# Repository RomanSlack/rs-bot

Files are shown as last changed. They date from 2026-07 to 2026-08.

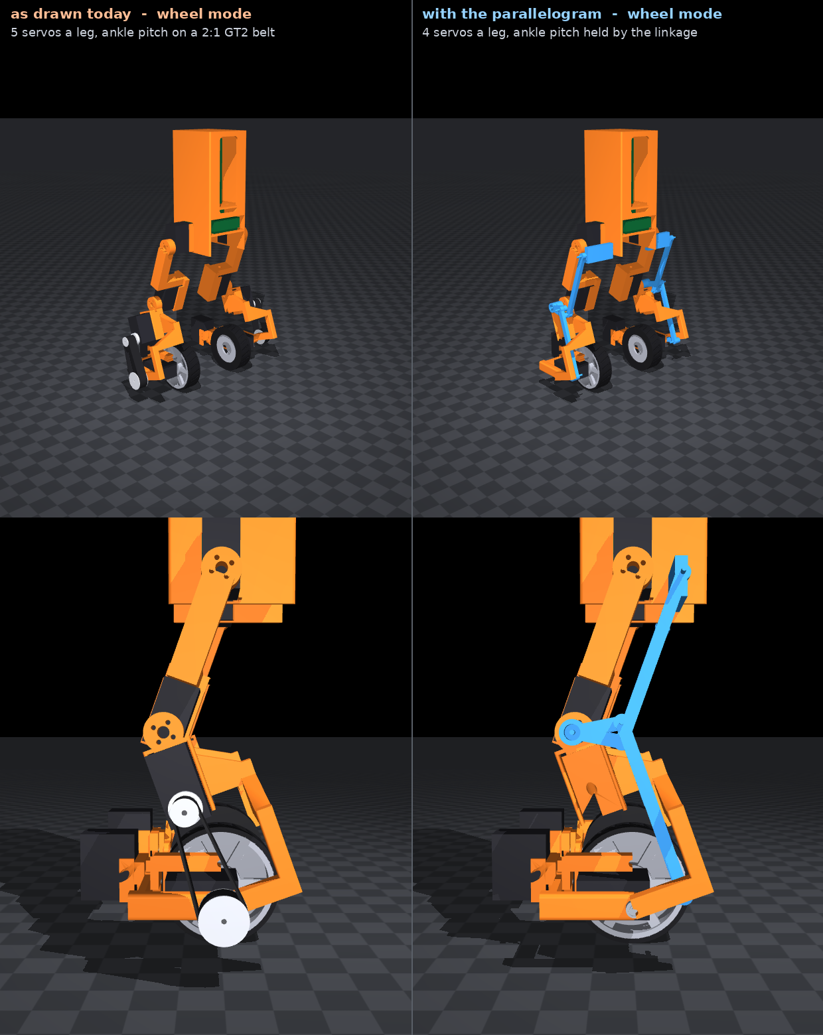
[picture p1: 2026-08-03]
renders/servos-before-after-wheel.png

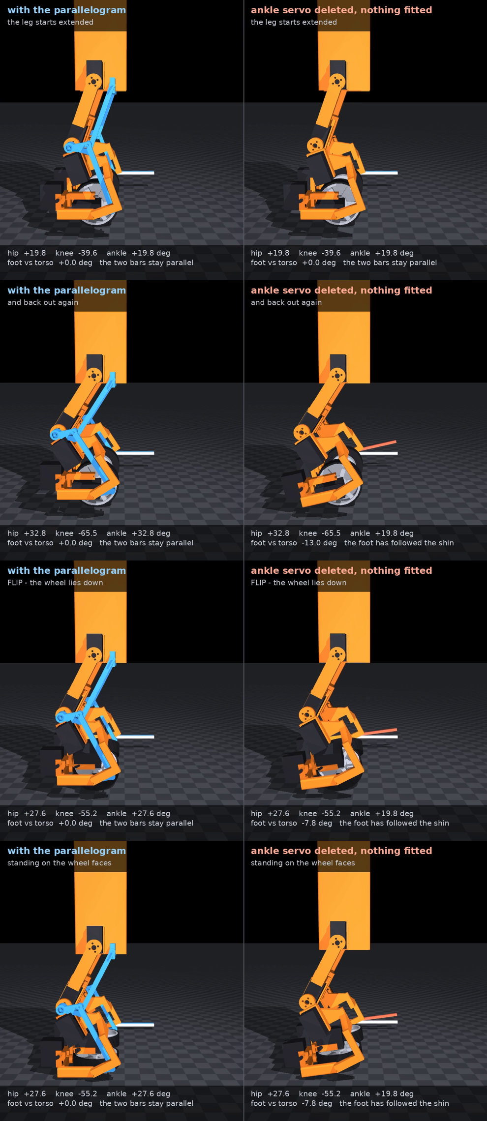
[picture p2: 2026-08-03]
renders/linkage-explained.png

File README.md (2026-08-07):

# rs-bot

A desk-scale wheeled biped whose wheels rotate flat to become its feet.
~43 cm tall, ~1.80 kg.

It balances on two wheels like a tiny Handle, and when it needs to hold still
or manipulate something, each ankle rolls 90 degrees: the wheels lie down and
their 80 mm faces become the soles. It then stands there statically with the
balance loop switched off. That transition is the point of the project - a
wheeled biped that can stop fighting its own balance loop before it reaches for
something - and the wheel-as-foot trick means it costs one joint per leg and no
extra parts.

Nothing here is bought yet. Everything runs in MuJoCo.

## The point: one shot

**The digital twin is the deliverable, not a preview of it.** The goal is a
model so exactly 1:1 with reality that the physical build happens once: parts
ordered once, printed once, assembled once, working. No revision rounds.

That is a real constraint rather than an ambition. The operator has no printer,
so every part comes from a service at real money and one to two weeks per
attempt, and a part that has already been built around is worse than that. The
cheapest place to find a mistake is in the model, and the only mistake that
costs nothing is the one caught before the order.

So the rule the whole repo is organised around:

> **Anything the model asserts about the real robot has to be traceable to
> something measured.** A number that came from a product listing, a
> screenshot, or somebody's guess is a bug that has not surfaced yet.

This is why the verification layer in `cad/` is bigger than the parts it checks:
interference and clearance through both poses, fastener specification, driver
access, tolerance stack-up, cable routing, FEA in five materials, printability.
It is also why the status reports read as lists of things that turned out to be
wrong. Finding those is the work.

Two examples of the failure mode, both real and both from 2026-08-01. The wheel
carried a Ø20.00 pocket for a horn that measures Ø19.93, which would have made
most wheels unable to accept the part they bolt to. And forty M2 screws went
into servo case holes whose positions no drawing publishes, with four different
parts each guessing a different pattern. Neither was visible until somebody put
calipers on the real servo.

## Status

**Stages 0 and 0b (sim) - done.** Balances, drives, rejects shoves, and flips
its wheels flat to stand for 87 s with the controller off.

Gear backlash is modelled, and it is the finding that most changed the plan.
The balancer needed much lower gain plus a low-pass on the wheel command,
without which it limit-cycles through the deadzone. The passive foot stance
needed a low-gain ankle loop too, until the ankle servo was deleted: a passive
parallelogram holds the foot level mechanically and does it better than the
loop did, standing 10/10 at 4 deg of lash where the servo managed 2/10 at 2.
See [docs/backlash.md](docs/backlash.md) and
[docs/deleting-the-ankle-pitch-servo.md](docs/deleting-the-ankle-pitch-servo.md).

Stage 1 hardware has not started.

## Roadmap

Each stage has a hard exit criterion. Hit it and move on; don't polish stage N
because stage N+1 is scary.

| # | Stage | Exit criterion | State |
|---|---|---|---|
| 0 | Sim balancer | Rejects a shove, attitude recovery < 1 s | **done** |
| 0b | Sim foot transition | Flips to foot mode and stands, balancer off | **done** |
| 1 | Legs in hardware | Stands 5 min unattended, survives a poke, drives, squats | |
| 2 | Feet in hardware | 20 consecutive transitions both directions, zero falls | |
| 3 | Head camera | Teleop drive from the camera feed alone | |
| 4 | One arm | Picks up a can, 8/10 attempts | |
| 5 | Second arm | Autonomous policies | |

## Design commitments

These are fixed up front so stage 4 doesn't invalidate stage 1.

- **The whole skeleton is designed now, built in pieces.** The sim model already
  carries the arms, head and compute as torso ballast, so the legs are tuned
  against final inertia (1.80 kg) rather than a bare stage-1 mass.
- **STS3215-class serial bus servos throughout.** 2.9 N.m stall. The leg joints
  run position mode; the wheels run continuous rotation, which means the
  balancer gets a *velocity* command, not a torque. The controller is built
  around that constraint rather than pretending otherwise.
- **The wheel is the foot.** 5 DOF per leg - hip pitch, knee pitch, ankle
  pitch, ankle roll, wheel - but only FOUR servos: ankle pitch is driven by a
  passive parallelogram off the hip and knee, not by a motor. Nothing deploys, nothing folds out. Two earlier mechanisms
  with separate feet both failed for the same reason, recorded in
  docs/stage-0b.md.
- **No hopping.** Bouncing needs real torque control at ~1 kHz and QDD ankles.
  Static feet mode gets most of the value; hopping is a different robot.

## Layout

```
src/rsbot/model/rsbot.xml   MJCF model
src/rsbot/model.py          loading, leg IK, foot geometry
src/rsbot/balance.py        the balancer
src/rsbot/transition.py     wheel mode <-> foot mode state machine
src/rsbot/sim.py            headless rollouts, shove test
serve.py                    live sim in the browser: drag to orbit, scroll to zoom
render.py                   render a demo run to renders/*.mp4
scale.py                    true-scale still beside a 5 ft 9 in person
fitcheck.py                 do the real parts actually fit? (oriented-box audit)
tune.py                     coordinate-descent gain search
view.py                     native viewer (needs a working GLX display)
cad/shin.py                 build123d proof of concept: STEP + MuJoCo mesh
cad/linkage.py              the passive ankle parallelogram, drawn and swept
cad/linkage_dims.py         its geometry, with no build123d, so the sim can
                            import it too
cad/linkage_anim.py         it moving, beside a leg that has none
cad/fitview.py              the assembled robot in the browser, every gap
                            measured: toggle parts, explode, both poses
cad/servo_view.py           the servo model against the part on the desk
tests/                      exit criteria as executable checks
```

## Run it

```bash
uv run python -m pytest tests -q   # all exit criteria, ~20 min (the FEA)
uv run python serve.py             # live sim at localhost:8781, drive it around
uv run python -m cad.fitview       # the assembly at localhost:8783, gaps measured
uv run python fitcheck.py          # part interpenetration audit, both modes
uv run python render.py            # render a demo to renders/
uv run python tune.py              # re-tune balancer gains
```

Latest status report: [status/2026-08-06-status.md](status/2026-08-06-status.md).
Each one leads with what turned out to be wrong that day, which is the fastest
way back into the project.

## Documents

**What the sim proved**

- [stage-0.md](docs/stage-0.md) - the balancer numbers
- [stage-0b.md](docs/stage-0b.md) - the foot transition, and the two mechanisms
  that failed before it
- [backlash.md](docs/backlash.md) - the gear-lash results, and the finding that
  most changed the plan
- [hardware-readiness.md](docs/hardware-readiness.md) - actuator and
  control-rate margins. Are STS3215s enough, and how fast must the loop run

**The parts**

- [cad.md](docs/cad.md) - why build123d, and the route from sketch to real CAD
- [porting-a-link.md](docs/porting-a-link.md) - the method used to port each
  part, and the clearance rules every part is checked against
- [real-parts-in-sim.md](docs/real-parts-in-sim.md) - putting the CAD solids
  back into the physics model
- [materials.md](docs/materials.md) - what to print in, and why
- [mass-budget.md](docs/mass-budget.md) - where the 1.80 kg goes
- [stress.md](docs/stress.md) - FEA, per part, in five materials
- [assembled-strength.md](docs/assembled-strength.md) - the leg solved as one
  solid rather than part by part

**Buying it**

- [order-sheet.md](docs/order-sheet.md) - **the file that has to be correct on
  the day money is spent.** Quantities, part numbers, prices
- [bom.md](docs/bom.md) - the real parts, and what modelling them at full size
  revealed
- [road-to-order.md](docs/road-to-order.md) - what still blocks an order
- [before-you-order.md](docs/before-you-order.md) - what has been verified, and
  against what

**How this project goes wrong**

- [how-checks-fail.md](docs/how-checks-fail.md) - **read this before trusting a
  green result.** Twenty-three ways a check here has lied, all of them things
  that happened. The parts are in better shape than the things that verify them

**Questions settled, so they stay settled**

- [deleting-the-ankle-pitch-servo.md](docs/deleting-the-ankle-pitch-servo.md) -
  could a passive four-bar replace the ankle-pitch servo? Yes, and it stands
  10/10 in foot mode where the servo now manages 2/10. Drawn as a mechanism
  too: it fits, it beats the gear lash it replaces, and it needs one
  length-adjustable rod that nobody had thought of
- [deleting-the-roll-servo.md](docs/deleting-the-roll-servo.md) - could the
  wheel motor drive the ankle roll through a clutch? No, and the reason is not
  the one you would guess

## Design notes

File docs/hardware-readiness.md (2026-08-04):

# Hardware readiness

Two questions decide what to buy. Both now have answers from the sim.

## 1. Are STS3215s enough? Yes.

Stall is 2.9 N.m; safe continuous is roughly 0.6-0.9 N.m. What matters is RMS,
not peak, because peaks are what stall torque exists for.

| joint | RMS (worst case) | peak | % time > 0.9 N.m |
|---|---|---|---|
| hip | 0.08 | 1.68 | 0.0% |
| knee | **0.36** | 2.90 | 0.4% |
| ankle pitch | 0.07 | 1.63 | 0.1% | (no servo: a linkage holds it) |
| ankle roll | 0.18 | 0.92 | 0.0% |
| wheel | 0.38 | 2.90 | 2.6% |

Worst case is the flip cycle plus driving. The knee is the hardest-working
joint at 0.36 N.m RMS, comfortably inside continuous. Knee and wheel do touch
the 2.9 N.m clamp, but for 0.1-1.8% of the time - transient, which is fine.

**No actuator upgrade needed.** The design fits the cheap servo class.

## 2. How fast does the control loop need to run? At least 50 Hz.

This one shapes the electronics, because 8 servos on one TTL bus will not give
you 200 Hz if you read every joint back: a sync-write of 8 positions is quick,
but 8 individual position reads are 8 round trips. It was 10 until the
ankle-pitch servos were deleted (`docs/deleting-the-ankle-pitch-servo.md`),
which takes two round trips off the worst case and does not change the
conclusion below.

| control rate | balancing | flip round trip |
|---|---|---|
| 200 Hz | 1.2 deg pitch, 17 mm drift | ok |
| 100 Hz | 1.3 deg pitch, 17 mm drift | ok |
| 66 Hz | 7.3 deg pitch, 235 mm drift | ok |
| 50 Hz | 7.6 deg pitch, 289 mm drift | ok |
| 33 Hz | 13.8 deg pitch | ok, marginal |
| 25 Hz | 18.8 deg pitch | **falls** |

100 Hz is comfortable, 50 Hz is usable but visibly worse, 25 Hz is dead.

**The architecture that follows:** the balancer only needs the IMU (local,
fast, I2C/SPI) and the two wheel velocities. It does not need to read the leg
joints back at loop rate. So sync-write all 8 commands, read only the 2 wheel
servos, and run at 100 Hz. Reading every joint every cycle is what would drop
you into the 33 Hz danger zone.

## What sim still cannot tell you

Listed so nobody mistakes a green test suite for a working robot:

- ~~Backlash~~ **now modelled** - see [backlash.md](backlash.md). Short version:
  wheel mode survives 1-2 deg after re-tuning but wobbles badly, and foot mode
  falls over while standing. Lash is a purchasing spec, not a detail.
- **Serial bus latency and jitter.** Modelled only as a control rate, not as
  variable delay.
- **Speed-dependent servo torque.** The model is a flat 2.9 N.m clamp; real
  servos lose torque as they speed up.
- **Terrain.** A perfect friction plane. No carpet, no USB cable, no lip
  between floorboards. At 80 mm wheels these are all obstacles.
- **Yaw and steering.** Never tested. The controller has no differential drive
  and the robot has never turned.
- **Roll disturbances.** Passively stable by wheel separation, never tested.
- **Foot-mode disturbance rejection.** Passive only; tips at 0.35-0.45 N.s.
  The ankle strategy that would fix it is unbuilt.

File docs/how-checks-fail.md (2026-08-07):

# How checks fail here

This project's whole method is to catch mistakes in the model, because the
model is cheap and a reprint is a fortnight. That method has one weakness, and
it is not the one you would expect: **the checks are less trustworthy than the
parts.**

Every entry below is something that actually happened in this repo, most of it
inside two days. They are written as patterns rather than as history, because
the specific bug is never the one you will hit next. Read this before you trust
a green result, and before you write a new check.

---

## 1. A check that cannot fail

The oldest rule in the repo and still the most productive. `cad/fasteners.py`
reported "every servo screw runs along its servo's mounting axis" in green for a
week while three joints had screws that never touched a servo. It was not lying.
It checked that a hole was PARALLEL to a shaft, and read as though it checked
that the hole ARRIVED at one.

**The test:** break the thing on purpose and confirm it screams. Every check
here that was control-tested that way survived; two were rewritten because the
first version passed a deliberately broken input.

## 2. A check nobody runs

`cad/assemble_check.py` had `stack()` and `sweep()`, and
`uv run python -m cad.assemble_check` called neither. The flip sweep on real
solids - written the day before, and described in that day's report as "the
first time this robot has been swept on its actual geometry" - only ever ran
when somebody imported it by hand and remembered to.

A check nobody runs is not a weaker check, it is an absent one, and it is worse
than absent because the documents list it among the checks that pass.

## 3. A check whose INPUT is wrong

The one that cost the most. Every FEA in this repo ran on meshes containing
inverted elements - tets with a flipped Jacobian - for weeks. Six of the seven
parts. An inverted element contributes negative stiffness, so the matrix is not
positive definite, and **the solves mostly converged anyway**: they returned
numbers that looked like results and went into every strength document here.

On valid meshes the roll bracket is at 99% of PA6-CF, not the 70% that had been
published. The error was entirely in the direction that makes a part look safe.

> A check validates its logic and forgets its input. That is the same failure as
> #1, one layer down: `fasteners.py` checked a hole's direction and not its
> destination; the FEA checked its solver and not its mesh.

**Ask of any check: what does it consume, and who checks that?**

## 4. A threshold set to the number you already have

`test_every_screw_can_be_reached_when_it_is_fitted` asserted
`len(blocked) <= 4`, with a paragraph explaining why four unreachable screws
were acceptable. They were not unreachable at all - the check that produced the
4 was broken. The bound had been set to whatever was being reported, which is a
screenshot of a bug, not a threshold.

Its opposite is also on record and is the good case: a tight assertion
(`mass == 1.875 +/- 0.003`) is the one that would have caught a 32 g divergence
immediately, while a comfortable range (`1.83 <= m <= 1.90`) absorbed it in
silence for a fortnight.

**A bound wide enough to be comfortable is a bound that will absorb a real
fault.**

## 5. A number in two files

The repo's own rule, and it kept being broken. `SHAFT_X` = 12.5 mm was wrong in
FOUR separate files in two days: the sim, `cad/toolaccess.py`,
`cad/envelope.py`, and again in `ankle.ROLL_SV`. Each time it was fixed
somewhere, nobody asked who else had a copy.

**When a number turns out to be wrong in one file, the question is not whether
it is fixed. It is who else has a copy.**

The fix is a pure-data module both halves import: `cad/servo_dims.py`,
`cad/wheel_dims.py`. No build123d, so the physics can import it too.

## 6. A constant with no uses

`WHEEL_TIRE_T = 0.008` in the sim said the tread was 8 mm. The CAD builds 3 mm.
It survived because **nothing read it** - one definition, zero uses, wrong by
5 mm, in the file that describes the robot to the physics. `SEG_MASS` was the
same: dead, stale, and sitting under a comment reading "Derived, not estimated",
which sent an agent chasing the wrong constant for an hour.

A constant with no uses is not harmless. It is a wrong answer waiting for the
first person who trusts it, and it reads as verified because it sits among
numbers that are. It is the mirror image of #1: a fact nobody consults is never
contradicted.

## 7. Incrementing a number you have not checked

`docs/order-sheet.md` said 183 g of printed structure. Updating it for five new
cradles, an agent wrote 197 g by adding to the number already there. It is
341 g. The 183 was the legs only, quoted as if it were the robot; the chassis
alone is 135 g and had never been in it.

The error was not the increment, it was the base. **Adding to a stale number
makes it look freshly checked and puts your name on it.**

## 8. The reason a check gives for not checking something

`cad/twin.py`'s bought-box check shipped with one constant excused, on the
stated grounds that its frame was not pinned against the sim. That sounded
rigorous. It was disproved by the first line of the measurement: two of the
three axes matched to a thousandth of a millimetre, which is not something an
unverified frame conversion does. The third axis was 6.8 mm out.

**An exclusion deserves the same suspicion as an assertion.** Name what is not
covered, in the check's own output, so the excuse can be argued with.

## 9. Prose does not re-run itself

`docs/road-to-order.md` blocked an order on two thin margins, 86% and 94%. Both
numbers were stale before anyone worried about them: the parts had been
redesigned since. An item can sit on a blocking list long after the thing it
describes has stopped being true.

Status reports are worse, not better, because they are dated and therefore look
authoritative. One recorded "mass went 1875 g to 1904 g" - into a document,
while the model stayed at 1875 for a fortnight.

**Any number in a document is a copy. See #5.**

## 10. Nondeterminism makes every other check unreliable

gmsh's parallel mesher gave 49217, 49278 and 49370 nodes from the same STEP with
identical settings. While that was true, "does this converge" was a coin flip
and nothing downstream could be diagnosed at all. Single-threaded meshing costs
time and buys the ability to ask a question twice.

**A check whose answer changes between runs is not a check.** Fix that first;
everything else is guesswork until you do.

## 11. Look at it

Three faults were found by a human looking at a screen and none of them by
anything measuring: servos drawn as bounding boxes, a belt drawn as its
clearance envelope, and a shaft floating in front of the right tyre because
MuJoCo reports that joint's axis negated and the code trusted the sign.

The last one is the point. The geometry the CHECKS ran on was fine. The viewer
was assembling a different robot, and `0 interfering pairs` was true of both.

> **A check can measure the right number and still be looking at the wrong
> robot.**

Screenshot what you build. `cad/fitview.py` is the assembly viewer; headless
Chrome will render it, and it takes a minute.

## 12. An envelope is not a part

`cad.belt.swept()` is a box the width of the big pulley spanning the whole
centre distance. That is the correct shape for "what must nothing else occupy"
and a useless shape for "what does this look like". Likewise the sim's servo
BOXES are the conservative shape for interference and hide the horn end, the
boss end and the connector.

**An envelope is a claim about empty space. A part is a claim about material.**
Know which one you are holding, and never let a viewer show one while a check
uses the other without saying so.

## 13. Model the bought parts, not just the printed ones

The shin and the ankle yoke had nothing between them, because the joint - a
623ZZ bearing and a 3 mm shaft - existed only as HOLES. So did every non-servo
bought part: bearings, shafts, pulleys, belts, horns. Ten line items, about $80,
none of them drawn.

Nothing could then ask whether a shaft was long enough for its bore. Drawing
them produced the answer in a minute: 14.0 mm and 15.5 mm, against an order
sheet that said "30 mm, or cut from stock".

**The parts that do the assembling are the ones nobody checks.**

## 14. Measure the thing, not something adjacent to it

Two wrong ways to measure one shaft, in one afternoon:

- probing MATERIAL along the joint axis gave 120 mm, because it ran the length
  of the wheel and the roll servo. A shaft passes through HOLES, not material.
- scanning for coaxial bore FACES missed the shin's bore entirely and gave
  10 mm for a 14 mm joint. The bore is real: 350 mm3 of material rings it and
  its wall is exactly `SHAFT_R` from the axis.

Both were plausible, both were confidently wrong, and the second failed silently
in the safe-looking direction. When a measurement surprises you, measure it a
second way before believing it.

## 15. Symmetry: solve one side, mirror it

`cad/wiring.py` reached this first - choosing each side's cable pairing by
"whichever two are closest" picked a different pair on the right - and the roll
shaft repeated it, because MuJoCo reports the right ankle-roll axis negated.

The robot is symmetric. **Solve the left, mirror it, and never read a per-side
sign out of the physics** when the CAD already states where something lives.

---

## 16. An index that quietly changed meaning

A test injected a fault by writing `m.eq_data[0]` and `[1]`, which were the two
ankle tendons on the day it was written. Then the parallelogram's own bodies
went into the sim and added three equalities per leg, so index 1 became a
ROD's coupling. The test went on running, went on passing, and went on
reporting that the robot survived build offsets that used to floor it - because
it was no longer injecting the fault it named.

Nothing about the test changed. The world it indexed into did.

**Anything addressed by position is a bet that nothing will ever be inserted
before it.** `_write_stance` in `src/rsbot/model.py` was written for exactly
this reason - the lash joints interleave, so a hand-written qpos vector
scrambles the moment backlash is switched on - and the lesson had not been
carried across to the equalities. Look up by NAME.

## 17. A constraint that mj_forward does not solve

`fitcheck.pose()` clears qpos, writes the joints it knows by name, and calls
`mj_forward`. That is the whole posing mechanism behind every geometric check
in the repo. When the linkage's rods and idler became real bodies held by
equality constraints, `pose()` did not know their names, so it left them at
zero - the rods hanging straight down off their pins - and `mj_forward` did not
correct it, because forward kinematics does not run the constraint solver.

It was caught by a check written the same hour, which reported 32.8 degrees of
angular divergence with the POSITIONS exact to the micron. That signature is
worth remembering: right place, wrong attitude, means something set a position
and not an orientation.

**A constraint is not a fact about the model, it is a thing the solver does.**
If you did not run the solver, it has not happened.

## 18. "One connected group" is not "assembled"

Two parts count as joined when the gap between them is zero. A gap of zero is
also what you get when they are twenty-five millimetres INSIDE each other, so a
connectivity check happily reports one object for a robot that is
interpenetrating. It was the control test for `connected()` that showed this:
shoving a rod deep into its neighbours did not disconnect it, and only moving
it 250 mm clear did.

Connectivity is also only REACHABILITY. A part hanging on by a single 0.04 mm
graze passes, and so does a pin that enters one of the two parts it joins and
misses the other - which is exactly what this repo's linkage pins were doing,
engaging 3 mm of a 6 mm idler and none at all of the chassis fin, while every
check reported one connected group.

**Three questions, and they need three checks:** does it touch (connectivity),
does it touch without overlapping (interference), and is it HELD - how much of
the pin is actually inside the bore. `cad.linkage.assembled()` is the third
one, and it is the only one that found anything.

## 19. A bounding box cannot tell a fork from a slab

The thigh was one box in the physics model, 20 x 16 x 98, and it had been that
box for the whole life of the project. `cad.twin` measured it at **71.4% backed
by CAD material** and passed it, because the threshold for "ok" is lower than
that and 71% reads like a rounded-off part.

It was not a rounded-off part. The real thigh does not run straight down: it
reaches AROUND the knee servo to a fork on the INBOARD side, because the
outboard band is where the shin's hub has to be. The box described the outboard
spine running down to z = -102, and the real outboard material stops at -74.
The missing 28 mm out of 98 is the 28.6% - the box was describing material on
the wrong side of the leg.

**What finally showed it** was not twin. It was a new part: the idler's stub, a
boss on the knee axis. `fitcheck.py` had it 3.3 mm inside the thigh. On the
real solids the two are **22.11 mm apart** at every pose, so the collision was
entirely against material that does not exist.

Then the fix went wrong the same way twice more, and both are worth keeping:

- Replacing the one box with an inboard **plate** put it 10 mm inside the knee
  servo, while the real solids intersect at 0 mm3. The plate came from probing
  the solid and reading each slice's **bounding box**, and the y profile is
  continuous straight across the servo pocket - a fork and a slab have the same
  bounding box. The x profile is what distinguishes them: material at
  |x| = 12.5..15.3 with air between. Three boxes, not one.
- The fork wall then sat 0.5 mm inside the servo. `cad/thigh.py` says
  `SERVO_Y_LO = SERVO_Y_HI - SERVO_H  # inboard face, y = -20.4` and that
  comment has been wrong since `servo_dims.HEIGHT` was corrected to 36.50: the
  face is at -21.5. The comment was not load-bearing on its own. It became
  load-bearing the moment a second file was written off it.

**The lesson is not "raise twin's threshold".** It is that a percentage-backed
number says how MUCH of a box is wrong and says nothing about WHERE, and
"where" is the whole question when a part reaches around something. A box that
is 71% backed and 29% on the wrong side of the leg scores the same as a box
with a chamfer it does not model.

## 20. A check that got greener because its subject left the set

`cad.linkage.ground()` measures how close the linkage comes to the floor in
foot mode. It walks `placed()`, which walks `SOLIDS`. When the yoke arm stopped
being a linkage part and became a feature the yoke prints, it left `SOLIDS` -
correctly - and the check went from **8.1 mm to 13.0 mm**.

Both numbers were true and neither was the point. The arm really did rise, from
its section going 8 to 6 and its root moving off the ankle-pitch shaft bore. But
about half that move was the check no longer looking at the lowest thing the
linkage puts near the floor. The arm is the entire reason the function exists:
its docstring says so, and says the inboard route for stage 2 was ruled out
because the only arm that cleared the roll bracket dropped to 1 mm.

**The tell is the direction.** A refactor that moves a part from one owner to
another should not change a measurement. When a number improves on a change
that was supposed to be neutral, the question is not "what got better" but
"what is no longer in the loop". `mounts_placed()` puts the three mount
features back in front of `ground()`, for measurement only, and the lowest part
it reports is the arm again.

The same session had the mirror image of this: the whole-robot mass assertion in
`tests/test_foot.py` went stale for the third time on a change that was correct,
because it was a literal. It now derives from `cad.masses.table()`. A number
that goes stale every time something legitimate happens is not a tight check, it
is a second copy.

## 21. A global answer to a local question

"Is the robot one connected object?" has been green in three different checks
for the life of this project. `fitcheck.connectivity()` says one group at 4 mm,
`cad.assemble_check.connected()` says one group at 0.05 mm on the real solids,
and `tests/test_foot.py` asserts both.

All three were true while **four of the six servos were held by nothing** - the
two hip servos 0.400 mm off the chassis and the two roll servos 0.400 mm off the
ankle yoke, touching no part of the robot anywhere.

They stayed green because union-find over the whole robot at once cannot ask a
local question. Each floating servo is still joined to the assembly through its
own output horn, and a horn touching a servo is a real contact, so the graph
stays connected. What is broken is not the graph. It is that a servo and the
part it seats against belong to the SAME RIGID BODY, move as one lump, and have
nothing between them.

`cad/floating.py` asks the two local questions instead:

- **a rigid body has to be one piece.** Union-find WITHIN a body, at a seam
  rather than a running clearance.
- **a connector has to reach both ends.** A shaft touching one body drives
  nothing.

The two have opposite tells, which is why one check could not do both: a
bracket that touches one body is fine, a shaft that touches one body is not.

**Two traps in writing it, both of which produced a confident wrong answer:**

- Reach has to be TRANSITIVE. The first version reported all four ankle shafts
  as reaching nothing, because a shaft does not touch the parts it joins - it
  touches the BEARING pressed into them. Four false alarms is how you teach
  somebody to ignore a check.
- The control test has to push in a direction that actually separates. Nudging
  the knee servo 2 mm into its cradle left the gap at 0.000, because the thigh
  wraps it on three sides. The check looked broken and was not.

**And note what the fix to one of these was already called.** `cad.fasteners`
has been reporting "worst is 1.30 deg" of servo capture preload for weeks, and
that 1.3 degrees IS this 0.4 mm, measured from the other end. Two checks
describing one fault in units that do not obviously match is its own way of
staying invisible.

## 22. A valid solid is not a printable mesh

A seating face was added to the chassis to stop a floating servo, drawn to meet
the two cradle walls exactly at their starting edge. The solid was correct -
`floating` seated the servo at 0.000, `assemble_check` found no interference,
`fitcheck` was clean in both modes, `twin` weighed it to the milligram. Then
`printability` reported **four open edges**, and it was right: the wall met each
cradle wall along a single EDGE and no face, which is a valid B-rep and a
non-manifold mesh. A print service's own checker rejects that before it quotes,
which here costs a fortnight.

Nothing lied. The geometric checks answer "is this solid well-formed and where
it should be", and it was. Only `printability` reads the exported STL, so only
`printability` asks "will this tessellate into a closed surface". A zero-width
crack interferes with nothing, weighs nothing and stays connected, so it is
invisible to every check that works on the solid rather than the mesh.

Two things fall out of it. **A face added against existing structure has to
overlap it or share a full face** - abut it along an edge and every geometric
check stays green while the mesh comes apart. And it was caught only because the
loop re-derives the state instead of trusting the last report: the run that
introduced it never called `printability`, so the summary would have read green
while `docs/order-sheet.md` pointed at an STL no service would take.

> **Well-formed where the checks look is not the same as manufacturable.** The
> mesh is a different artifact from the solid, and only one check sees it.

## 23. A check that read a stale copy of the thing it checks

The whole-leg FEA (`leg_assembly`) meshes `leg_assembly.step` off DISK, and
nothing in the test suite regenerates it - only `cad.stress` main does. So for
an unknown stretch it was solving an OLD fused leg while the parts underneath it
moved, and passing. It looked like the most expensive check in the repo; it was
grading a file. Putting a bore in the yoke and regenerating the STEP is what
surfaced it, and the failure was not the bore.

That is #3 again - a check validates its logic and forgets its input - one layer
out: not a wrong number fed in, a wrong VERSION of the geometry, silently,
because the input is a build artifact nobody re-made. The tell is that a
geometry change nowhere near the leg's load path changed whether the leg solved
at all.

**And what the fresh geometry then exposed:** the mesher emitted ONE orphan node,
referenced by no element, and a single node with zero stiffness leaves the whole
stiffness matrix singular - the leg came back 34706 connected nodes plus 1, and
the solve returned nan. The convergence GUARD (added after the inverted-element
episode, #3) caught it correctly, but the fault it named - "the constraint set
is too small" - was not the fault. A stray node is a mesh artifact, not a
structural fact, so `cad/fea.solve` now pins orphan nodes; a genuinely
disconnected CHUNK still trips the same guard, which is the disconnection that
would actually matter.

**The wrong fix got built first, and that is the lesson inside the lesson.** The
bore was blamed, a whole "defeature the yoke for the global mesh" mechanism was
written to route around it - and the defeatured leg failed identically. The
thing you changed last is the loudest suspect and usually the wrong one; the
control (does it still fail WITHOUT my change) is what pointed at the orphan.

## The shape of all of them

Every entry here is the same mistake in different clothes: **something was
believed because it was displayed.** A green line, a printed table, a dated
report, a constant sitting among verified constants, a rendered picture.

The question that catches them is not "is this check passing". It is:

> **What would this look like if it were wrong, and would I be able to tell?**

If the answer is "it would look exactly like this", you have not checked
anything yet.

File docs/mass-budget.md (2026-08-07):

# Mass budget

Target is the **final** robot, arms and all. The sim model carries the
not-yet-built parts as torso ballast so the legs are sized and the balancer is
tuned against real inertia from day one. On the stage-1 hardware build this is
literal: a ~600 g block where the arms and head will go.

**These are now derived, not estimated.** Run `uv run python -m cad.masses`.
Each body is its printed structure (volume x PETG x infill) plus the servos
whose *cases* bolt to it plus the bought parts it carries. The shin uses its
real CAD mass from `cad/shin.py`.

| Item | Count | Each | Total |
|---|---|---|---|
| Leg servos, STS3215 | 8 | 55 g | 440 g |
| Printed structure (chassis, thighs, shins, yokes, brackets) | | | 325 g |
| The parallelogram, printed: rod, idler, rod | 2 | 17 g | 34 g |
| Arm/head ballast + IMU (stage 4) | | | 605 g |
| 3S pack | 1 | 180 g | 180 g |
| Wheels, printed body + TPU tyre + horn | 2 | 55 g | 110 g |
| Pi 5 | 1 | 45 g | 45 g |
| Bus adapter | | | 10 g |
| **Total** | | | **1749 g** |

**1907 to 1800 g on 2026-08-03**, and every gram of it is the ankle-pitch
servos and their belt drive coming out: 2 x 55 g of servo and 2 x 34 g of
pulleys, belt and shafts, against 2 x 35 g of linkage going in. See
`docs/deleting-the-ankle-pitch-servo.md`.

The parallelogram row said **2 x 35 g** until 2026-08-04 and the rows did not
sum to the total, which nobody noticed because the total was written out
separately. 35 g a leg was right when the fin, the stub and the arm were loose
solids of their own; they are features of the chassis, the shin and the yoke
now, so they are inside the row above and the rods and idler alone are 17 g.

**Then 1800 to 1770 g on 2026-08-04**, which is the shin giving up the MOUNT
for the servo that had already gone: a standoff, two cradle walls, an end wall
and a clearance pocket, 53.05 cm3 down to 45.11, about 9 g a leg. It sat there
for a day with a note on it saying it was dead. Nothing failed while it did,
because dead material is conservative in every check this repo runs - which is
exactly why nothing was going to remove it on its own.

**Then 1770 to 1771 g on 2026-08-05**, the only ADDITION in the run: a seating
face on each of the four servos that were held by nothing - an end wall under
the two hip cases, a datum wall on the two roll cradles. About 1 g total, and it
buys the load path a face to bear on instead of 0.4 mm of air.

**Then 1771 to 1749 g the same day**, and no part moved: the printed structure
had been weighed at PETG's 1.270 g/cm3, the density it was COSTED in, while it
is ordered in PA6-CF at 1.19 (docs/materials.md). That density was in five files
and is now in one, cad/material.py, imported by the CAD and the sim alike. The
22 g is the correction. The balancer was re-checked against it, not assumed:
still stands 60 s and rejects a 1.0 N.s shove (tests/test_stage0.py).

That 107 g is not just lighter, it is lighter IN THE RIGHT PLACE. It came off
the far end of the leg, and foot mode now survives 4 degrees of gear lash where
the same linkage on the old mass failed at 4 ten times out of ten.

The printed structure came in at **380 g against a 400 g estimate**, which is
much closer than the 165 g this page claimed until 2026-08-02. That 165 was the
legs only, quoted as if it were the robot: the chassis alone is 135 g and was
never in the figure. Estimating structure by eye overshoots, but not by the
two-to-one this page was advertising.

> **Still quoted at PETG's 1.27 g/cm3, and these parts are ordered in PA6-CF at
> 1.19.** About 26 g the model carries that the robot will not. Not fixed,
> because the material is not settled: `road-to-order.md` item 8 put three PA12
> variants back in play when the roll bracket went from 99% to 55%.

## How that maps onto the sim model

A servo case bolts to the body **proximal** to the joint it drives, which is
what fixes the old error of leaving 100 g in the shin for a wheel servo that
actually lives on the roll bracket, 110 mm further out.

| Body | Mass | Printed | Carries |
|---|---|---|---|
| torso | 1109.9 g | 135.1 g | 2 hip servos, Pi, pack, adapter, IMU, 600 g ballast, 2 linkage fins |
| thigh x2 | 102.9 g | 41.1 g | knee servo, linkage rod 1 |
| shin x2 | 54.1 g | 40.4 g | linkage rod 2, idler and stub. NO SERVO |
| ankle x2 | 70.8 g | 13.7 g | ankle-roll servo, linkage arm |
| rollbracket x2 | 62.6 g | 7.6 g | wheel servo |
| wheel x2 | 54.8 g | - | body, tyre and horn |
| **Total** | **1800.4 g** | **340.7 g** | |

The shin is the row that moved: **128.9 g to 54.1 g**. It was carrying a 55 g
servo and 34 g of belt drive out at y = 84.5, and it is now the lightest link
in the leg. Its centre of mass moved 22.7 mm and most of its inertia went with
the pulleys.

> **The sim agrees with this table to a tenth of a gram**, per body, checked by
> `uv run python -m cad.twin`. It has not always: it weighed 1874.8 g for a
> fortnight against a CAD that said 1907, because `SEG_INERTIA` is pasted from
> `cad.inertia --emit` and nobody re-ran it. What follows is that history.
>
> ~~The sim does not agree with this table.~~ It weighed 1874.8 g, because
> `SEG_MASS` in `src/rsbot/model.py` was a hand-copied snapshot that nobody
> re-ran after the servo cradles landed. `cad.twin` failed on it per body. The
> table above is the CAD's, which is what gets built; the gap was open on
> purpose because closing it changes what the balancer was tuned against.

## Torso fore/aft trim

The torso mass is offset fore/aft so the standing CoM lands over the wheel
axle. It is **solved for at load time** rather than hardcoded (`model.load()`):
build once, measure the offset, shift the torso, which is exact in one pass
because the relationship is linear.

This is not cosmetic. Any residual offset becomes a permanent standing lean
that eats lean authority. When the feet were separate parts that parked behind
the wheel, the untrimmed CoM sat 5.7 mm aft and forced a 1.2 deg lean; nulling
it cut the residual standing lean from 2.1 to 0.8 deg. Solving for it means
changing the leg can no longer silently reintroduce the error.

On the real build, this is where the battery goes. Expect to trim it again on
hardware once the arms are on, since they move the CoM forward.

### What the correction cost

Losing 337 g made the robot twitchier, and the gains are mass-dependent: the
old set fell over at 2 deg of lash once the robot got lighter. Re-tuned, and
shove rejection settles at 1.0 N.s rather than 1.4 - the same impulse is a
larger velocity change on a lighter robot.

**The +120 g is the cost of the wheel-flip foot.** It buys an ankle roll joint
per leg, and that joint is what turns the wheel into an 80 mm foot centred
under the axle. It replaces every separate foot part: no soles, no struts,
no pads.

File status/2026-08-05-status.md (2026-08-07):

# 2026-08-05 - the four floating servos get a face, and one seat cannot be where you want it

## What turned out to be wrong

Nothing new. This is the top item off 2026-08-04's list, taken and closed: the
four servos that were held by nothing now bear on a seating face. The two hip
servos sat 0.400 mm off the chassis and the two roll servos 0.400 mm off the
ankle yoke - `CRADLE_CLEAR` on every wall, so the cradle you drop a servo into
located it on no axis at all, and the torso's load into the legs ran through two
M3 screws in air.

`cad/floating.py` found it, and it is now green. Two independent checks that
describe the same fault from other ends moved with it, which is the confirmation
that matters more than floating going quiet:

- `cad.fasteners.capture()` went from **1.30 deg to 0.20 deg** at the hips and
  **0.10 deg** at the roll cradles. That 1.3 deg WAS the 0.4 mm, measured as
  free rotation about the shaft; closing the gap closes the angle.
- `cad.assemble_check` reports the servo cases seated, not floating.

The robot is **1771.0 g**, sim and CAD agreeing. Up 1 g, the only addition in
the run.

## The fix, and why the two ends are not the same fix

The good mounts already in the repo - the thigh's knee servo, the roll bracket's
wheel servo - seat on a face PERPENDICULAR to the cradle walls, flush, so the
case bottoms on it. A flush WALL cannot do this job: with print tolerance at
+/-0.3 mm a wall drawn to the case size can come out 0.3 mm small and the servo
will not go in, which is the whole reason `CRADLE_CLEAR` is 0.4 and exceeds it.
The seat has to be a face the servo meets along its INSERTION direction, not one
it is pressed between.

**The hip (chassis) took the clean version.** The servo's lower z face already
had 2.5 mm of side plate reaching past it (`SIDE_Z0 = HIP_SERVO_Z[0] -
CRADLE_WALL`), so an end wall flush at `HIP_SERVO_Z[0]` seats the case and sits
OUTSIDE the servo's interference envelope, below it. `assemble_check` passed it
without comment.

**The roll (ankle) could not.** The first attempt reached the "servo face" ring
in to the case body output face at x = -61.4 - correcting a real latent bug,
because the ring had been built to the envelope's spline TIP at -58 and stood
3.4 mm off the servo seating nothing. It seated the case at 0.000 on the real
mesh, and `floating` and `fitcheck` were happy. Then `assemble_check` reported
**828 mm3 of overlap** with the roll servo, constant across the flip, and it was
right: the servo's interference BOX is solid from -94.5 to -58, so any seat that
touches the case output face on the shaft axis is buried inside the box on one
side or the other. The spline is round and clears in reality, but the envelope
reserves that corner, and a seat is not allowed to spend reserved space on the
strength of "the real part is thinner here". That is how-checks-fail #12 in a
new place: the mesh checks and the box check disagree on a shaft-axis seat, and
the box is the one to believe.

So the roll seat is the other legal option: **one wall is the datum**. The +y
wall goes flush to the case, the -y wall keeps `CRADLE_CLEAR`. The servo slides
in along its shaft (x), not down between the walls, so a flush wall is not a
press fit - it just gives the case a face to register against, and the opposite
wall still lets it drop in. The bottom face, which would have been the
thigh-style perpendicular seat, is the one the foot-mode floor rules out, and
the yoke already carries that note.

## Where the numbers live

- Seating geometry: `cad/chassis.py` (hip end wall) and `cad/ankle.py` (roll
  datum wall), each with the reasoning in place.
- Mass and inertia followed the material: `cad.inertia --emit` regenerated
  `SEG_INERTIA` for `ankle` and `torso` in `src/rsbot/model.py`, so the sim
  weighs what the CAD builds. `SEG_MASS` above it is still dead (only
  `cad/twin.py` mentions it, to say so); left as found.
- `docs/order-sheet.md` and `docs/mass-budget.md` went 1770 to 1771 g. Both
  totals are `cad.masses`, summed, not carried forward.

## The hip seat left the chassis STL non-manifold, and only one check saw it

The hip end wall was drawn to +/-xi, which is where the two cradle walls START.
That met each wall along a single EDGE at z = HIP_SERVO_Z[0] and nowhere else,
and an edge-only join is not a surface a printer can slice: the export came out
with four open edges, the exact thing a print service's own checker rejects
before it quotes. `cad/printability.py` was the only check that caught it.
`floating`, `assemble_check`, `fitcheck` and `twin` were all green on the same
geometry, because a crack that is zero millimetres wide interferes with nothing,
weighs nothing and stays connected. The fix runs the wall out to +/-xo so it
shares a FACE with each cradle wall and the outer x face runs continuous, the
way those walls already meet the side plate.

Two things this is worth remembering for. First, a seating face added against
existing structure has to OVERLAP it or share a full face - abut it along an
edge and the solid is still valid in every geometric check but the mesh is not.
Second, this was caught only because the loop says re-derive the state rather
than trust the last report: yesterday's run never called `printability`, so the
regression would have sat green in the summary while the one file that has to be
correct on order day pointed at an STL no service would take.

## The robot was weighed in the wrong plastic, in five files

The printed structure was quoted at PETG's 1.270 g/cm3. It is ordered in PA6-CF
at 1.19 - `docs/materials.md` settled that months ago, "the only material that
passes" - and the only reason the mass used PETG was that PETG "is what those
parts were costed in". Costed in is not ordered in. Weighing a part off its cost
basis made the whole robot read **22 g heavy**: 1771 g against a real 1749.

The number was in five files - `cad/chassis`, `cad/ankle`, `cad/thigh`,
`cad/shin` and `cad/masses` - all reading 1.270, which is the repo's own rule
broken five ways and four places waiting to drift. It is now in `cad/material.py`
alone, a leaf module the CAD parts and the physics mass table both import, the
way `servo_dims` and `wheel_dims` already hold the numbers that used to be
copied. `cad.twin` confirms sim = CAD at every body and 1749.0 g total.

The mass feeds the balancer, so it was re-checked and not assumed: all 14 of
`tests/test_stage0.py` pass at the new mass - stands 60 s unattended, rejects
0.35 and 1.0 N.s shoves both directions, tracks 0.25 m/s, steers. The margin the
lighter robot spends is already inside the thresholds, which were themselves
re-measured the last time it lost mass rather than relaxed.

## The state

```
cad.floating        nothing floats, 0 connectors unreached
cad.drives          every servo on its joint
cad.twin            every box backed, 1749.0 g sim = 1749.0 g cad
cad.fasteners       worst preload 0.70 deg (the knee, unchanged); hips 0.20, rolls 0.10
cad.assemble_check  clean: 0 interfering, seated, stack holds, flip sweep clean
fitcheck.py         0 interpenetrating pairs, both modes, all 26 flip poses
cad.printability    every part closed and printable (chassis manifold again)
cad.wiring          6 runs clear, worst pose change 9.4 mm
cad.toolaccess      every screw reachable
test_stage0         14/14, balancer holds at 1749 g
```

`cad.floating` is green for the first time since it was written. Nothing in the
run is red.

## What is still open, in rank

Two closed since 2026-08-04 (the floating servos; the PETG-vs-PA6-CF mass), and
one struck as never real:

- STRUCK: "the shin's forward carrier reaches y = 136, moving it in is a
  kinematics decision." Measured on 2026-08-06 and the shin runs y = 15..76: the
  bearing is at PITCH_Y = 71, where the envelope forces it, and there is no
  y = 136 member to bring in. The 136 was belt-era and went stale the day the
  belt left (2026-08-03); it rode two status reports as an open item before
  anyone built the part and looked. Corrected in cad/shin.py. This is #9 - a
  number in a doc is a copy - caught being repeated by the loop itself.

1. Backlash unmeasured on real hardware, which everything above is quoted
   against.
2. `cad.stress` has never solved a linkage rod, and the FEA still runs on solid
   material while the parts print at 60% infill - a strength question the mass
   fix did not touch but sits right next to it.

## Not done, and worth saying

I did not stand up headless Chrome to screenshot `cad/fitview.py` this run. The
"look at it" rule earned three faults that no measurement caught, so this is a
gap - but the seating here is exactly what `floating` measures and paints red,
it is green, and two other checks agree from other ends. A render would confirm
the servos look seated rather than merely reading as seated; it is worth a
minute next time the viewer is up.

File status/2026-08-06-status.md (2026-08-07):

# 2026-08-06 - two open items were measured, and neither was real

## What turned out to be wrong

The bugs today were in the OPEN-ITEMS LIST, not the model. Two things carried on
it as work-to-do were checked against the geometry for the first time and struck.
Both had been believed because they were written down, which is this repo's
oldest failure (how-checks-fail.md #9), and this time the loop itself was the one
repeating them: each rode a status report forward without anyone measuring.

## The shin does not reach y = 136

The list said "the shin's forward carrier reaches y = 136; bringing it in moves
the ankle-pitch axis, a kinematics decision." Built and measured, the shin runs
**y = 15..76**. The ankle-pitch bearing is at PITCH_Y = 71, where cad/envelope.py
forces it - the only outboard band is 56..80, inboard collides with the wheel or
pairs the two bearings 6 mm apart. There is no y = 136 member to bring in.

The 136 was belt-era. The ankle-pitch belt once shoved the bore ~53 mm off axis;
the belt was deleted 2026-08-03 and the bore came back on axis, but the comment
in cad/shin.py did not follow, and from there it copied into the 08-04 and 08-05
lists. Corrected at the source, in the comment that started it.

## The FEA does not overstate strength - it was already knocking infill down

The list said the FEA "runs on solid material while parts print at 60% infill, so
the strength may be optimistic the way the mass was heavy." It is not. cad/stress
already multiplies the ALLOWABLE by 0.60 for every FDM material (`knockdown()`),
so a part fails at 60% of its coupon ultimate. That is the conservative
direction, and the shin's PA6-CF utilisation is 66% in-plane / 67% interlayer
against a knocked allowable, not against solid.

What WAS wrong was one line of the comment, and it is the kind worth catching:
the header claimed the 0.60 knocked "both strength and stiffness". Only strength
was. Deflection was solved at solid E - correctly, because bending stiffness
lives in the solid perimeters at the extreme fibre, so solid E is close to real
and a lower bound, the same footing docs/assembled-strength.md already uses. The
comment made a reader believe the deflections were conservative when they are a
lower bound. Had someone "fixed the code to match the comment" - which was the
first thing tried here - every FDM deflection would have nearly doubled (the shin
from 6.8 to 11.3 mm) into a number the part does not have. Fixed the comment, not
the code: net behaviour unchanged, no deflection number moves.

One inert straggler noted, not fixed: cad/stress carries PA6-CF at 1.15 g/cm3
while cad/material.py now says 1.19. It is a different value for one material in
two files (#5), but `rho` is set and never read in the stress pipeline (#6), so
it is dead. Resolving which datasheet is right is a coupon question, not a
guess to make today.

## And the linkage rod finally got solved - and a test caught up to the mass

"cad.stress has never solved a linkage rod" had sat on the list for a fortnight,
and it turned out to be half a real gap and half a category error. A two-force
member fails two ways, and only one of them belongs in cad.stress at all:

- COMPRESSION is buckling, which a linear-static field solver cannot see. That
  is why the rod never went into cad.stress, and it was right not to. Euler in
  cad/linkage.loads() has always had it, at **20.7x** on the live load.
- TENSION pulls on the pin EYE, whose stress concentration the net-section hand
  calc in the comment could not give. THAT is the number nothing had solved.
  cad/linkage.rod_stress() points cad.fea at the rod for the first time and gets
  **1.2 MPa, 2% of the knocked PA6-CF allowable**, mesh-converged at 1.3 and
  1.6 mm. So "sized by buckling, not stress" is a solver result now, and both
  modes have a test: test_the_rod_eye_is_far_below_allowable and
  test_the_rods_are_nowhere_near_buckling.

Solving it surfaced the actual bug, which was in the test, not the rod. The
buckling test's docstring said "sized on the MEASURED torque, not a literal"
while the code passed `torque_nm=1.082` - a literal, and a stale one: the live
survey reads **0.95 N.m** since the robot dropped to PA6-CF, so the frozen force
was 14% high (how-checks-fail #20, the very trap the docstring named). It now
calls the live survey, which is 10 s and not the "couple of minutes" its
comment feared, and asserts the buckling MARGIN rather than a copied force that
went stale on every mass change. The stale 38.7 N / 18x in cad/linkage.py's own
comments were corrected to the live 34 N / 20.7x.

## And the fasteners were a paper claim the geometry never backed

Checking whether the CAD holes match the bolt list - the kind of paper-vs-solid
link this project exists to police - turned up the sharpest gap of the day. The
BOM orders **16 M2.5 heat-set inserts**, and there is not one **3.5 mm bore in
any part to seat them**: `M25_INSERT_R` was defined and used nowhere (a dead
constant, #6), and where the schedule says "insert in chassis" the chassis cuts
a 2.7 mm clearance hole straight through. Every part-to-part joint - chassis
assembly, Pi mount, ankle-pitch retention - has no thread. Print today and it
stops at assembly, a fortnight gone. The `order-sheet.md` fastener table had
drifted the other way too: 40 M2 case screws deleted with the capture cradles,
and missing the 8 M3x6 horn centre screws and 4 M3x12 + 4 nuts the rod clamp
needs, while claiming to be "generated by cad.fasteners".

Nothing caught it because `audit()` checks servo-screw ALIGNMENT (the horn
holes, which exist) and `bom()` counts inserts off the schedule - intent, never
geometry. Two checks now do: `fasteners.inserts_seated()` asks the solid for a
bore per insert and reports the shortfall (chassis 12, yoke 2), and
`fastener_order()` plus a test holds the order sheet equal to the schedule.
Both control-tested - the insert check detects a real blind bore and ignores a
clearance hole - and the shortfall was PINNED in tests/test_fasteners.py the way
the floating servos were.

**Then the bores went in and the interface closed.** Three ways: the 4 Pi
standoff bores were cut (an insert in the standoff top, not the 2.7 mm
through-hole that matched no fastener); the 8 "side plates -> top" inserts were
DROPPED, a joint a one-piece fused chassis does not have, taking the order from
16 inserts to 8; the 4 yoke inserts became two radial M2.5 set screws per pair,
retaining the ankle-pitch shaft from the boss's exposed +x face. `inserts_seated`
reads empty, the pin flipped to `== []`, and it verified clean - interference
through the flip, meshes manifold, sim = cad at 1748.9 g.

Placing them extended `toolaccess`: it had flagged the insert bores as
unreachable because it treated them as driver-driven screws. A heat-set insert
is a bench operation - pressed with an iron before assembly, its screw arriving
from the mating part - exactly like the horn screws it already excused. It now
excludes them, its control test still catches a real slab across a driver, and
what the exclusion does NOT cover (the yoke set screws, driven in the assembled
robot with a hex key) is named in the check itself.

## The state

The fastener insert interface is closed end to end (checks + geometry); the rod
solved; the PETG->PA6-CF mass; two comment-and-test fixes. Mass 1748.9 g,
sim = cad.

```
cad.floating        nothing floats
cad.drives          every servo on its joint
cad.twin            every box backed, 1748.9 g sim = 1748.9 g cad
cad.assemble_check  clean
fitcheck.py         0 interpenetrating, both modes, 26 poses
cad.printability    every part closed
cad.stress          allowable knocked 0.60 for infill; shin 66/67% of PA6-CF
cad.linkage         rod eye 2% of PA6-CF (fea), buckling 20.7x (Euler), live load
cad.fasteners       inserts_seated empty; order sheet = bom(); every screw specified
cad.toolaccess      every screw reachable (inserts excused as bench ops)
cad.fea             solve pins orphan mesh nodes; leg_assembly converges again
pytest              109 passed (full suite, incl. the FEA)
```

## And placing the yoke inserts uncovered a stale FEA the suite had never noticed

The two yoke set-screw bores went in - radial from the boss's exposed +x face
onto the pitch shaft - and `inserts_seated` reached empty. But the full suite
then failed two stress tests, and chasing it was the real work of the day.

The whole-leg FEA (`leg_assembly`) reads its STEP off disk and nothing
regenerates it, so it had been solving a STALE fused leg and passing (#23).
Regenerating it to current geometry, the solve went singular. The bore was the
loudest suspect and the wrong one: a "defeature the yoke for the global mesh"
workaround, built first, failed identically. The real cause was ONE orphan node
the mesher emits, zero-stiffness, enough to make the matrix singular.
`cad/fea.solve` now pins orphan nodes (a disconnected CHUNK still trips the guard
that matters), the defeature was reverted, and the leg converges at 36 k nodes.
The net of the whole saga is small and right: the inserts plus a one-block fix
in the solver.

## What is still open, in rank

The insert bores closed today, and with them the last thing the model could
settle on its own. What is left needs a physical part:

1. Backlash unmeasured on real hardware, which every margin above is quoted
   against. A bench measurement, not a model change.
2. The infill knockdown (0.60 on the allowable, solid E on stiffness) is a
   defensible assumption, not a measured one. It wants one printed coupon.

Both are answered by the $30 validation order in road-to-order.md, not by more
simulation. The digital twin has, as far as its own checks can prove, converged.

Item 1 is the last thing the model can settle on its own - I said yesterday
everything digital was settled and this proved it wrong, which is the point of
checking the paper against the geometry. 2 and 3 need a bench or a coupon that
no simulation produces.

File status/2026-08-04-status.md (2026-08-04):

# 2026-08-04 - four servos were held by nothing, and no check could see it

## What turned out to be wrong

Someone looked at the assembly viewer and said parts were still floating. Every
check was green. They were right and the checks were not wrong either, which is
the whole content of this report.

**Four of the six servos touch no part of the robot.** The two hip servos sit
0.400 mm off the chassis, the two roll servos 0.400 mm off the ankle yoke. Not
in a cradle bolted through a face - off it, with air on every side.

```
   vkneesv_l -> thigh_l          0.000 mm     seated
   vwhlsv_l  -> rollbracket_l    0.000 mm     seated
   vhipsv1   -> torso            0.400 mm     held by nothing
   vrollsv_l -> ankle_l          0.400 mm     held by nothing
```

0.400 is `CRADLE_CLEAR`. A cradle is cut 0.4 mm oversize on purpose so the
servo drops in, and that part is correct. What is missing is a seating FACE:
two of the four mounts have one and two do not, and a cradle you can drop a
servo into is not a cradle that locates it.

## Why nothing caught it

Three checks ask "is the robot one connected object" and all three were right
to say yes. `fitcheck.connectivity()` at 4 mm, `assemble_check.connected()` at
0.05 mm on real solids, and two tests asserting both. A floating servo is still
joined to the assembly **through its own output horn**, so the graph stays
connected. The graph was never the problem.

The problem is that a servo and the part it seats against are the SAME RIGID
BODY. They move as one lump and have nothing between them. Union-find over the
whole robot at once cannot ask that, because it is a local question and the
answer it gives is one global number.

There is a second reason it stayed hidden, and it is worse: **`cad.fasteners`
has been reporting this for weeks in different units.** "Worst is 1.30 deg" of
servo capture preload IS this 0.4 mm, measured from the other end. Two checks
describing one fault in units that do not obviously match is its own way of
being invisible.

## The tool

`cad/floating.py`, and it asks the two local questions instead:

- **a rigid body has to be one piece** - union-find WITHIN a body, at a seam
  rather than at a running clearance. `loose()`.
- **a connector has to reach both ends** - a shaft touching one body drives
  nothing. `unreached()`.

They need to be separate because the tells are opposite. A bracket that touches
one body is fine; a shaft that touches one body is not.

`cad/fitview.py` paints whatever it reports **red**, with a "held by nothing"
panel at the top and click-to-isolate onto the part and the face it should be
meeting. That is the half that matters: a list of names in a terminal makes you
hunt for the part, and the reason these survived is that nobody could see them.

**Two traps in writing it, both of which produced a confident wrong answer.**

- Reach has to be TRANSITIVE. The first version reported all four ankle shafts
  as reaching nothing, because a shaft does not touch the parts it joins, it
  touches the BEARING pressed into them. Four false alarms is how you teach
  somebody to ignore a check.
- The control test has to push in a direction that actually separates. Nudging
  the knee servo 2 mm into its cradle left the gap at 0.000, because the thigh
  wraps it on three sides; the check looked broken and was not. `+y` gives
  0.085 mm and is reported. `tests/test_floating.py` pins the working nudge and
  says why.

Runtime is 1.7 s after a bounding-box prefilter, so it runs inside the viewer
rather than being a thing you remember to do.

## And the shell for the servo that is not there

The ankle-pitch servo was deleted on 2026-08-03. Its mount outlived it by a
day: `STANDOFF`, two cradle side walls, an upper end wall and a clearance
pocket, all holding a part that is not on the order sheet.

**53.05 cm3 to 45.11**, about 9 g a leg, off the part with the least mass left
to give. The robot is **1769.8 g**, sim and CAD agreeing.

`cad.twin` caught the consequences immediately and in the right direction:
`vankstand_l` went to 0.0% backed, NOT IN THE CAD, and the shin read 8.8 g
heavy until `SEG_INERTIA` was regenerated.

Three things fell out of it:

- `cad/assembly.py` was still drawing an ankle-pitch servo, placed off
  `shin.STANDOFF`. The last viewer showing a robot that does not exist.
- The shin can mesh at 2.2 mm again, 43 680 nodes. It had been bracketed at
  2.25 yesterday because the knee stub pushed it past `fea.MAX_NODES`; that is
  not a mesh fix, the part is simply 8 cm3 smaller.
- `docs/mass-budget.md`'s parallelogram row said 2 x 35 g and the table did not
  sum to its own total. 35 g a leg was right while the fin, stub and arm were
  loose solids; they are host features now, so the rods and idler alone are
  17 g. The order sheet still said **1.907 kg**, two changes behind.

## What is still open, in rank

1. **The four floating servos.** A seating face on the chassis and the ankle
   yoke, the way the thigh and the roll bracket already have one. This is the
   1.3 deg capture preload on the old list, now with a number in millimetres
   and a check that fails until it is fixed.
2. The shin's forward carrier - FARM, FPOST, CROSS, DROP, BACK - reaches
   y = 136 because the deleted belt forced the ankle-pitch bearing out there.
   Bringing it in MOVES THE ANKLE PITCH AXIS, so it is a kinematics decision
   rather than a tidy-up. Flagged, not taken.
3. Printed mass quoted at PETG's density for parts ordered in PA6-CF, ~26 g.
4. Backlash unmeasured on real hardware, which everything above is quoted
   against.
5. `cad.stress` has never solved a linkage rod.

## The state

```
cad.floating        4 servos held by nothing, 0 connectors unreached
cad.drives          every servo on its joint
cad.twin            every box backed, 1769.8 g sim = 1769.8 g cad
cad.fasteners       worst preload 1.30 deg
cad.wiring          worst change 9.4 mm
cad.assemble_check  1 connected group at 0.05 mm, 0 interfering, stack clean
fitcheck.py         0 interpenetrating pairs, both modes, all 26 flip poses
cad.linkage         every pivot made, every mount seated, arm 13.0 mm off the floor
cad.toolaccess      every screw reachable
cad.printability    every part printable
```

`cad.floating` is the only one of those that is red, and it is red on purpose.

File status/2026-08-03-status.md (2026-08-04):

# rs-bot status report

**2026-08-03** · 87 tests green · **handoff.** The one part that blocked an
order went from 99% to 55% for 1.5 mm of web, the bought hardware that actually
holds this robot together got modelled for the first time, and a passive
parallelogram beat the ankle servo it would replace by 10/10 against 3/10.

Previous: [2026-08-02](2026-08-02-status.md), which is long and worth reading:
it is the day every check in the repo turned out to be less trustworthy than
the parts.

---

## Read these first

- `docs/how-checks-fail.md` - seventeen ways a check here has lied, all of them
  things that happened. Read it before trusting a green result.
- `.claude/commands/goal.md` - the loop, and the check list with runtimes.
- This file's **Open** section, which is ranked.

## What is true right now

Every check passes. `uv run python -m pytest tests -q` is **87 passed**, about
22 minutes. `drives`, `twin` (all three of its checks), `assemble_check` (all
four), `fitcheck`, `wiring`, `toolaccess`, `printability`, `fasteners` and
`servo` are all clean, and so is `linkage`, which is new.

Two servers, both useful:

```
uv run python serve.py          :8781  drive it, flip it (F), shove it (space)
uv run python -m cad.fitview    :8783  the assembly, every gap measured
```

`cad.fitview` takes about four minutes to come up per mode because it exports 53
meshes and measures every pairwise gap. That is a wart, not a hang.

## What changed since the 08-02 report

### The roll bracket stopped blocking the order

It was at 99% of PA6-CF, converged, and over in all three PA12 variants. It is
at **55%**, and passes in all four.

```
web 4.0 mm   56.6 MPa   99% PA6-CF   118/126/135% in the PA12s
web 5.5 mm   31.4 MPa   55% PA6-CF    66/ 70/ 75%
```

Stress in a bending plate goes as 1/thickness, so the last 1.5 mm was worth 44
points. Hub radius was tried first and is not the lever - 8 to 12 mm moves it
99% to 97%, so it was never a concentration, just too little section. The 1.5 mm
came out of the yoke's post, which was 6.0 mm housing a 4.0 mm bearing.

**Three separate yoke boxes referenced the old web face and only one moved with
it.** `assemble_check` found the other two at 477 mm3 and 45 mm3, and `twin`
found the sim's post box still describing the 6 mm part at 37.9% backed. None of
that was visible in the diff.

### The bought hardware exists now

`cad/hardware.py` is new. Bearings, shafts, pulleys, the belt and the ten horns
were on the order sheet and drawn nowhere, so the shin and the ankle yoke had
literally nothing between them and nothing could ask whether a shaft was long
enough for its bore. They are in the CAD and in the sim, and the belt's 2:1 is a
MuJoCo equality constraint rather than an animation - verified at ratio 2.00.

`cad.hardware.horn_joints()` is the check that came out of it: **8 of 10 horn
joints seat at 0.00 mm**, where all ten were failing and two were clashing
1.10 mm. That 1.10 is `HORN_OVERALL_T - SPLINE_PROUD`: parts were positioned at
the spline tip, and the horn finishes 1.10 mm past it. The thigh and shin got
horn pockets; the roll bracket's coupler face is now derived from the horn.

### A parallelogram beats the ankle servo

`docs/deleting-the-ankle-pitch-servo.md`. Foot mode, 15 s, 10 trials:

| lash | servo + ankle loop | parallelogram, no loop |
|---|---|---|
| 2 deg | 2/10 | **10/10** |
| 3 deg | 3/10 | **10/10** |
| 4 deg | 2/10 | 0/10 |

Control-tested: removing the ankle's lash alone is worth nothing (0/5 at 3 deg).
The linkage wins because it is a mechanical feedback path, not because it is
rigid. `load(parallel=True)` builds it as a tendon equality.

**And it found something worse.** `docs/backlash.md` records foot mode standing
at 2-3 deg with the loop on. It does not any more. That table was measured
against the old inertia, and `SEG_INERTIA` was regenerated from the CAD on
08-02. Correcting the mass distribution, which was right, **broke foot mode at
the lash the servos actually have.** The table is marked superseded in place.

## Open, ranked by what it costs at the bench

**1. Draw the parallelogram.** DONE later the same day, see below. It fits.

It is proven as a constraint and not as a
mechanism. It deletes the belt drive (which provably does not fit), 180 g, two
servos, the 4.40 mm pulley hub that is not a catalogue part, and the outboard
bearing that makes this robot 306 mm wide. Kinematics do not change:
`hip + knee + ankle = 0` is what is commanded today.

The corridor is found and there is only one. A 5x5 mm link swept knee to ankle
against the real obstacles:

```
x = 34, y = 36     12 mm3    essentially clear
x = 24, y = 36    432 mm3
everywhere else   774 - 2243 mm3
```

Aft and outboard, which is where the belt currently runs. Note the topology:
holding the foot parallel to the TORSO needs two parallelograms in series, one
beside the thigh and one beside the shin, not a single link.

> **The table above was never committed as code and it does not reproduce.**
> Re-swept from `cad/linkage.py`, the corridor is much wider than one cell and
> the answer is a different one: the linkage goes OUTBOARD at an offset of
> 30 mm, and inboard - which is where "y = 36" points - is where the yoke
> cannot be reached. The topology note was right.

**2. The hip and roll servos have no seating face.** Captured with 0.4 mm
clearance on every face, which is **1.85 deg of free rotation** at the hip, in a
10.1 deg tilt budget that already spends 2-3 deg on gear lash. Three of five
servos seat at 0.000; these two seat on nothing. Probably worth more to foot
mode than any control work.

**3. The wheel stands 4.40 mm off its horn.** `cad/wheel.py` documents the
intent - pocket floor on the plate, rim 0.5 mm clear of the boss face - and the
assembly does not match it. Closing it moves the wheel (track width, stance,
flip envelope) or the servo (kinematics), so it needs a decision.

**4. The belt drive is 2.23 mm underground in foot mode.** The axle sits at
`WHEEL_HALF_W` = 12.0 mm with the wheel flat and the 40T pitch radius is 12.73,
so it does not fit even with no flange. Item 1 deletes this rather than fixing
it; if item 1 is rejected, this becomes blocking and the only escape is a ratio
under 2:1.

**Sequencing.** Do 1 before 2 and 3. The shin and ankle get redrawn by the
linkage, and fixing their seating faces first means fixing them twice. Item 2's
hip half is on the chassis and is independent.

## Smaller things left deliberately

- The mesh build carries 2 more DOF than the plain one - the belt pulley bodies
  only exist when `meshes=True`. They are stub-mass and hard-constrained, so
  dynamically inert, but a twin whose DOF count depends on a display flag is the
  kind of split this project keeps getting bitten by.
- The ankle-pitch horn is not in the sim. It belongs on the `beltdrive` body,
  which only exists in the mesh build, so the export skips it.
- `solid()` still returns the wrong-variant STEP, oversized in z, so clearance
  checks stay conservative. Safe direction.
- Backlash is still unmeasured on real hardware and is still the number this
  design sits closest to. It needs 12 V and a TTL adapter, and there is no
  serial code in this repo.

## Nothing is committed

About 35 files. The two days' reasoning lives in this file, the 08-02 report,
`docs/how-checks-fail.md` and `docs/deleting-the-ankle-pitch-servo.md`.

---

# Later the same day: the parallelogram is drawn, and it fits

Item 1 above is done. `cad/linkage.py`, `tests/test_linkage.py`, and a section
appended to `docs/deleting-the-ankle-pitch-servo.md`.

**The headline: nothing collides, at any pose, on the real solids, over squat
and flip, both legs.** 32.3 g per leg against 89 g of ankle servo and belt
drive, so 113 g comes off the robot. Five pivots, three new printed parts, and
two features on parts that already exist.

## What turned out to be wrong

**The published corridor does not reproduce, and the code that found it was
never committed.** The table above says one cell is clear (x = 34, y = 36) and
everything else is 774 to 2243 mm3. Re-swept against the same solids, the
clear region is a band tens of millimetres wide, and it is on the other side of
the leg: the linkage goes OUTBOARD. That is not a small correction. Inboard
there is a 59 mm empty corridor between the legs and the rods fit in it
beautifully - and the ankle yoke cannot be reached from there at all, because
it has no material inboard of y = -6, the roll bracket sweeps y = -23..+24
through the flip, and the one straight arm that clears the bracket ends up 1 mm
off the floor in foot mode. Outboard, stage 2's arm is 30 mm of an existing
yoke member carried further forward.

**`rollout_deploy(parallel=True)` returned 0 of 10, not 10 of 10.** This was
the first thing tried, on the assumption that the flag reproduced the published
table, and it came back WORSE than the servo it replaces at both 2 and 3
degrees. The flag built the linkage and left the ankle ACTUATOR in, so the
STAND loop drove the ankle to one angle while the tendon held it at another.
The published 10/10 is real; reproducing it needed the caller to also switch
the ankle loop off, and nothing said so because the measurement was never
committed. `load(parallel=True)` now removes the ankle actuators, which is what
a parallelogram physically is, and the default config gives 10/10.

**`cad/belt.py`'s `JOINT_PEAK_NM = 1.68` is stale.** The measured design ankle
torque is 1.082 N.m. That literal predates `cad/loads.py` being able to produce
the number, and `loads.py` could not produce it either: `survey()` ranks a
whole wrench and reports the instant that peaks, which is not the instant the
joint's own axis peaks. `loads.pitch_survey()` and `design_pitch_torque()` are
new and are what a drive should be sized from. The belt is being deleted, so
the stale number is recorded rather than fixed.

## The number that was not on anyone's list

The linkage is bought to get rid of 2-3 degrees of ankle gear lash. Drawing it
splits that into three quantities that do not behave alike:

| | worst case | what it is |
|---|---|---|
| free play, printed 0.10 mm bores | **0.97 deg** | the same animal as gear lash |
| free play, a 623ZZ at each pin | **0.10 deg** | ditto, for $1.60 a leg |
| build offset, print +/-0.3 mm | **4.21 deg** | a fixed tilt, per leg |
| band spread after adjustment | **1.09 deg** | what no adjustment removes |

It wins the argument it was having, by 2x on plain bores and 20x on bearings.

**And it introduces a fault the servo version did not have.** 4.2 degrees of
fixed foot tilt is not lash - it is a part that comes out of the machine aimed
slightly wrong - and with no ankle actuator there is nothing left to trim it
with. In foot mode that is the torso standing 4 degrees off vertical with both
soles flat, and the two legs are free to be wrong in opposite directions.

> **One of the two rods has to be length-adjustable.** That is a requirement
> this design did not have this morning, and it exists because the thing got
> drawn. `tests/test_linkage.py` asserts the size of it so that shrinking it
> counts and forgetting it does not.

## Also worth knowing

- **Transmission angle** holds at sin >= 0.931 over the band. Which of the two
  idler pins goes high is not a free choice: stage 1 low and stage 2 high keeps
  the rods from crossing AND keeps stage 2's pin above the axle, which is 12 mm
  off the floor in foot mode. The other way round crossed the rods for 950 mm3
  and put the yoke arm on the ground.
- **Rod force 38.7 N against 705 N of buckling.** The rods are not the problem.
- **The chassis fin is the worst part of the design.** 79 mm off the side plate
  to hold stage 1's ground pin, and a pin that moves is a foot that tilts at
  2 deg/mm. As a round boss that is 0.7 mm and 1.3 degrees - more than the free
  play the mechanism is bought for. It is a 25 mm fin instead, at 0.1 mm, and
  it wants triangulating back to the plate.
- **The clearance check found four faults in its own subject** before it found
  any in the robot: four pairs of linkage parts sharing a y band by 430 to
  950 mm3, every one of them a rod's eye inside the thing it is pinned to. The
  parts now live in a five-slice stack across y. Two of the slices are set by
  the wheel and the wheel-drive servo, and two by the shin's ankle carrier.
- **And the clearance check had a hole of its own**, which is the day's best
  reminder that a new check is the least trustworthy thing in the repo. It
  built its pair list as one product with `if na >= nb: continue` to drop the
  duplicate self-pairs, and that name comparison silently threw away every pair
  whose partner sorted before `lk_`. Exactly one part does: `ankle`, the yoke,
  which is where stage 2 lives. It read as 13 poses of green for an hour. Fixed,
  still clean, and control-tested by moving stage 2 inboard into the flat wheel,
  which brings back 10 colliding pairs.

## Still open, and it is the same list plus one

The ranked list above stands, with item 1 struck out and this added:

**Fold the linkage into the parts it belongs to.** Three of its six pieces are
features of parts that already exist - the fin is chassis, the stub is shin, the
arm is yoke - and they are drawn in `cad/linkage.py` rather than cut into
`cad/chassis.py`, `cad/shin.py` and `cad/ankle.py`. Until that happens the
linkage is checked but not built, and `cad.stress`, `cad.twin`, `cad.fitview`
and the mass budget know nothing about it. That is also when the belt, the
pulleys, the ankle servos and the shin's outboard bearing carrier come out, and
when the robot stops being 306 mm wide.

**Nothing else moved.** `drives`, `twin`, `fasteners`, `wiring`,
`assemble_check` (all four), `fitcheck` and `printability` are all still clean,
and `printability` now covers the five new parts.

---

# Later still: the linkage is the robot now, not a proposal

Items 1 to 4 of the ranked list above are done, and the order sheet with them.
**1907 g to 1800 g, ten servos to eight, and every check green.**

## What turned out to be wrong

**The 10/10 foot-mode result was measured on a robot still carrying the servo
it had deleted.** The parallelogram lived in `cad/` and nowhere else: the sim
still had the ankle servo, the belt, and their 89 g a leg. So `cad.twin` -
whose entire job is catching sim-versus-CAD drift - was blind to the largest
divergence in the repo, and the headline number was measured against mass that
was supposed to be gone.

Taking it out properly made it better, not worse. Foot mode now stands **10/10
at four degrees of gear lash**, where the same linkage on the old mass failed
four ten times out of ten. The cliff moved from between 3 and 4 degrees to
between 4 and 5, against servos that have 2-3. Deleting 89 g from the far end
of the leg bought a degree of backlash margin, and no tendon in a constraint
could have told you that.

**The wheel's 4.40 mm standoff was written up as a decision about the robot's
proportions and it is a change to one part.** "Move the wheel and change the
track, or move the servo and change the kinematics." Neither. The horn's plate
sits entirely on the SERVO side of the seating face, so what was missing was
hub, and hub grows outboard into space the servo already occupies. The tyre
does not move; the track, the stance and the flip envelope are untouched. 8 of
8 horn joints seat now.

**The hip and roll servos do not "seat on nothing".** Measure the gap from
every servo to the part holding it and all eight come back 0.000 mm. They all
touch. Touching is not being located, which is the actual fault, and the
published 1.85 degrees had no code behind it. `cad.fasteners.capture()` rotates
each case about its own shaft until something stops it: **hip and roll 1.30
degrees, knee 0.70, wheel 0.10.**

**`cad/belt.py`'s JOINT_PEAK_NM = 1.68 was stale** - the measured design ankle
torque is 1.082 - and `cad/loads.py` could not produce that number either,
because `survey()` ranks a whole wrench and the instant a wrench peaks is not
the instant a joint's own axis peaks. `pitch_survey()` and
`design_pitch_torque()` are new.

**CRADLE_CLEAR was in four files.** They all said 0.4, which is what a second
copy looks like right up until it is not.

## Two checks that were wrong rather than merely stale

`tests/test_stage0`'s mass bound was a second copy of a number in
`cad/masses.py`. It asks the CAD now, so it cannot go stale on its own.

And a cliff test I wrote this morning ran ten trials that were the same trial
ten times: it varied the DURATION, which does not change the initial condition,
and passed at a lash the robot demonstrably cannot flip at. Fixing it produced
a finding worth more than the test: **standing in foot mode is not what lash
breaks, arriving in it is.** Dropped straight in, already flat, the robot
stands at 6 degrees. It cannot flip there.

## The number that decided the adjuster

The worst-case build offset is 4.21 degrees of fixed foot tilt and 4.21 on its
own says nothing. So it was measured, by injecting the offset into the tendon
equality - which is exactly what a mis-built linkage does, still rigid, just
holding the wrong number - and flipping at 3 degrees of lash:

| offset | both legs the same way | opposed |
|---|---|---|
| **4.21 deg** | 8/8 | **7/8** |
| 5.0 deg | 8/8 | 4/8 |
| 5.5 deg | 0/8 | 1/8 |

The worst case does not sit near the cliff, it is **already over** stage 2's
exit criterion of zero falls - and over in the direction two separately printed
legs actually go, which is opposed rather than together. Rod 2 is two clamped
halves now, +/- 3 mm, worth 6.08 degrees against the 4.21 it has to cover.

## What the servo mounts cost, priced rather than deplored

Capture slop is in series with the gearbox, so it adds to that joint's gear
lash:

```
3.0 deg gear lash alone            8/8
4.3 deg, with the worst capture    8/8
5.5 deg                            0/8
```

It does not break the robot, it spends the margin: 3 degrees of lash on its own
sits 1.5 degrees from the cliff and the worst capture is 1.3 of that. Not
fixed, deliberately - the clearance is 0.4 mm because the service quotes +/-0.3
and a tighter cradle risks not assembling, so the answer is a compliant preload
on one wall, and two of the four parts that needs are about to be redrawn.

## Still open, ranked

**1. Redraw the shin, and fold the three linkage features into their hosts.**
`lk_fin` is chassis, `lk_stub` is shin, `lk_arm` is ankle yoke. Until then the
order sheet describes a robot that cannot be assembled, and it says so.

The shin is the part with real work in it, and it is measured now rather than
guessed at. **It still carries the ankle-pitch servo's mount: STANDOFF is
9.40 cm3 of its 53.05, about 7 g a leg, plus two cradle walls** - a mount for a
servo that is not there. And its forward carrier (FARM, FPOST, CROSS, DROP,
BACK) only reaches y = 136 because the deleted BELT forced the ankle bearing
out there. Both come out together or the packaging gets re-checked twice.
`cad/envelope.py`'s bands are already wider than that file last reported.

Meanwhile the dead mount is real in the model, so every clearance and mass
number above is conservative rather than optimistic.

**2. The servo capture preload.** 1.3 degrees, priced above, on four parts.

**3. The printed mass is quoted at PETG's 1.27 g/cm3 and these parts are
ordered in PA6-CF at 1.19.** About 26 g the model carries that the robot will
not. Not fixed because the material is not settled - three PA12 variants came
back into play when the roll bracket went from 99% to 55%.

**4. Backlash is still unmeasured on real hardware**, and everything above is
quoted against it. It needs 12 V and a TTL adapter, and there is no serial code
in this repo.

**5. `cad.stress` has never solved a linkage part.** The rods are 18x from
buckling by hand calculation and no FEA has seen them.

---

# And last: the linkage is in the twin, not beside it

The parallelogram was drawn, checked, rendered and costed, and it lived in
`cad/` and nowhere else. The physics had its KINEMATICS as one tendon holding
`hip + knee + ankle = 0`, which is exact and invisible. Measured rather than
assumed, before starting:

```
sim mesh build   62 geoms,  0 of them linkage
cad/fitview.py   41 solids, 0 of them linkage
cad/twin.py      had never heard the word
```

So `serve.py` showed a robot with no parallelogram on it, the viewer whose
whole job is measuring every gap measured every gap except this mechanism's,
and the check that exists to catch sim-versus-CAD drift could not see the
largest new thing in the repo. This report has been calling the twin "two
models pretending to be one". There were **three**: `cad/linkage.py` had its
own private model and was the only thing that could see the linkage.

**Now:** the rods and the idler are real bodies on real hinges, carrying their
real mass and their real meshes. 17 bodies, 8 tendons, 8 equalities. `cad.twin`
weighs all six of them. `cad.fitview` measures 53 solids where it measured 41.
`serve.py` shows the mechanism moving.

## Four faults, and three of them were checks

**The physics started requiring build123d.** The first version imported
`cad.linkage` to find out where a rod's pin sits, and that module imports the
CAD kernel at module scope, so `load()` silently stopped working without a
dev-group dependency. Nothing failed loudly. `cad/linkage_dims.py` is the fix
and it is the third file of its kind, after `servo_dims` and `wheel_dims`.

**`fitcheck.pose()` left the rods hanging straight down.** It clears qpos and
writes the joints it knows by name; the linkage hinges are not among them, and
`mj_forward` does NOT solve equality constraints. So every geometric check in
the repo would have posed the linkage at zero. Caught by the new
`cad.linkage.sim_matches_cad()` on its first run: **32.8 degrees of divergence
with the positions exact to the micron**, which is what a wrong angle looks
like. Control-tested by flipping the idler's coupling sign, which gives 65.5.

**A test index that quietly changed meaning.** `_flip_with_offset` injected the
build offset into `m.eq_data[0]` and `[1]`, which were the two ankle tendons
right up until the linkage added three equalities a leg. After that index 1 was
a ROD's coupling, and the test reported 8/8 at offsets that used to floor the
robot, because it was no longer injecting the fault it named. By name now.

**And one number I had overstated.** With the offset injected properly, the
worst-case build offset comes back **8/8 both ways** on the bodies model, not
7/8 opposed as the tendon model said. So the adjuster is justified by about
1.3 degrees of margin, not by "already over the line". Corrected in
`cad/linkage.py` and in the test.

## One number that is now a model artefact, and is labelled as one

Putting the linkage in as bodies moved the flip's backlash cliff a long way
out. Part of that is real: 10.6 g came off the shin into bodies of their own,
which is the same mechanism that made deleting the ankle servo worth a degree.
Part of it is not:

```
                    5 deg   6 deg   7 deg   8 deg   10 deg
damping 1e-4         8/8     8/8     1/8     1/8     0/8
damping 0            8/8     4/8     4/8     0/8     0/8
```

Between about 5 and 8 degrees the answer depends on `LINKAGE_DAMPING`, a
modelling constant with no measurement behind it. **Nothing in that band is a
measurement.** The design point is: 3 degrees of gear lash plus 1.3 of servo
capture slop is 4.3, and that is 8/8 on both. The guard in
`tests/test_foot.py` moved to 10 degrees, which is 0 out of 8 either way.

## What the picture still shows, on purpose

`renders/sim_linkage.png` is the SIM's own mesh build, and rod 1's top pin
floats. That is correct and it is the open item made visible: the fin, the stub
and the arm are FEATURES of the chassis, the shin and the yoke, and they are not
cut into those parts yet, so the sim draws exactly what the CAD builds. The CAD
renderer (`cad.robot`) draws them because `cad/linkage.py` places them
separately; the sim does not, because there is nothing in `chassis.stl` to
draw. When they land in their hosts the two pictures will agree, and until then
the disagreement is the reminder.

## Asked of it: is everything realistically connected, or is anything floating?

Worth asking, and the answer was no in two places - neither of which any
existing check could see, because both read as **one connected group**
throughout.

**The four pins a leg were printed plastic.** `_pin_at()` ADDED a Ø3 spigot to
whichever printed part carried it, so the chassis fin, the idler and the yoke
arm each came out of the machine with a 3 mm plastic pin on them - while
`docs/order-sheet.md` listed eight 3 mm steel pins. Two descriptions of the
same joint, one of them unprintable at that diameter and shearing anyway. The
carriers get a bore now and the pins are bought parts.

**The idler had no bearing.** It sat 0.50 mm off its stub with nothing in
between - a Ø3 shaft inside a Ø10 bore and 3.5 mm of air - while the order
sheet listed the 623ZZ that goes there. `docs/how-checks-fail.md` #13 exactly:
the parts that do the assembling are the ones nobody checks, and I had just
repeated it twice at once.

**And once the pins were separate parts they were the wrong length.** Sized
when they grew off their carriers, they started AT the carrier's plane and ran
outward, which engaged 3 mm of a 6 mm idler and **zero millimetres of the fin**,
whose material stops exactly where the pin began. Every rod eye was fine; every
carrier was not. Both ends are derived from the two planes now, and
`cad.linkage.assembled()` measures how much of each pin is inside each part it
joins by intersecting an oversized pin with it:

```
lkpin_fin     in lk_boss    8.00 mm      lkpin_fin     in lk_rod1   6.00 mm
lkpin_idler1  in lk_idler   6.00 mm      lkpin_idler1  in lk_rod1   6.00 mm
lkpin_idler2  in lk_idler   6.00 mm      lkpin_idler2  in lk_rod2   6.00 mm
lkpin_arm     in lk_arm     6.00 mm      lkpin_arm     in lk_rod2   6.00 mm
lkbrg_idler   seated in lk_stub and lk_idler
```

Control-tested by shortening the fin's pin 1 mm, which drops that pivot to 2.00.

**And a whole-robot version**, `cad.assemble_check.connected()`: 63 solids, on
the real geometry, at 0.05 mm. `fitcheck.py` already asked this and asked it of
the sim's BOXES at a 4 mm threshold, which is a much easier question - a box is
bigger than the part it stands for and 4 mm of slack joins things that are not
touching. One group in both modes.

> **What it cannot see, learned from its own control test:** an OVERLAPPING
> part reads as connected. Shoving rod 2 twenty-five millimetres into its
> neighbours still gave "1 connected group", because a gap of zero is a gap of
> zero whether two parts are kissing or interpenetrating. It is a necessary
> condition, not a sufficient one; the interference check is the other half.

The pins and the bearing are in the sim too, as the cylinders they are, so the
picture no longer shows rods held by nothing.

## Then: "make sure everything is realistically connected and not floating"

The mount features went into their hosts (fin into the chassis, stub into the
shin, arm into the yoke), which is item 1 above, half done. Folding them in is
what surfaced the rest of this section, and none of it was the linkage.

**The thigh in the physics model was describing the wrong side of the leg.**

`fitcheck.py` put the new knee stub 3.3 mm inside the thigh. On the real solids
those two are 22.11 mm apart, at every squat depth and every point of the flip:

```
wheel  h=0.185   22.12 mm      foot   h=0.195   22.12 mm
wheel  h=0.207   22.11 mm      flip 32%          22.12 mm
wheel  h=0.215   22.12 mm      flip 50%          22.11 mm
                               flip 75%          22.12 mm
```

The thigh was one box, 20 x 16 x 98, sitting outboard at y = 15..31 and running
down to z = -102. The real thigh's outboard material **stops at z = -74**: below
that it crosses to a fork on the inboard side, y = -30.5..-21.5, because the
outboard band at the knee is where the shin's hub has to be. 28 mm of a 98 mm
box, on the wrong side of the leg, for the whole life of the project.

`cad.twin` had been reporting that box at **71.4% backed, ok** the entire time.
It was not wrong: 28.6% of it is unbacked and 71.4% is above the bar. A
percent-backed number says how much of a box is wrong and nothing about where,
and "where" is the entire question for a part that reaches around something.

It is now four boxes, and the two corrections on the way there are the useful
part:

- The first replacement was one inboard **plate**, and it reported 10 mm inside
  the knee servo while the real solids intersect at **0 mm3**. The plate was
  built by probing the solid and reading each slice's bounding box, and a fork
  and a slab have the same bounding box: the y profile runs continuously across
  the servo pocket. The x profile is what tells them apart, material at
  |x| = 12.5..15.3 with air between, and that is the servo sitting in the fork.
- The fork wall then landed 0.5 mm inside the servo, because it was placed off
  `cad/thigh.py`'s `SERVO_Y_LO ... # inboard face, y = -20.4`. That comment has
  been wrong since `servo_dims.HEIGHT` was corrected to 36.50; the face is at
  -21.5. Harmless while nothing read it. Not harmless once a second file was
  written off it. Both boxes are now hung off the servo's own inboard face, so
  they abut it by construction, and the comment is fixed.

```
   thigh   vthigh_l         98.7% backed   was 71.4%
   thigh   vthighfork_l     99.0% backed
   thigh   vthighcheek0_l   94.3% backed
   thigh   vthighcheek1_l   94.3% backed
```

**The remaining eight fitcheck hits were the box model having no bores.** The
bearing pressed into the idler, and the knee stub through that bearing. Both
measured on the real solids before anything was exempted:

```
   idler & bearing       0.00 mm3   gap 0.000 mm    press fit, touching
   idler & shin + stub   0.00 mm3   gap 0.500 mm    the recess in the stub root
```

`cad/linkage.py`'s `clearance()` is what actually checks those pairs, on solids,
over 13 poses and both legs, bought parts included. Control-tested by deleting
the 0.5 mm recess from the stub: the solid sweep reports **735 mm3**, so
exempting the pair in the box model gives up nothing.

**Where it stands now.** Everything green, re-derived rather than quoted:

```
cad.drives          every servo is on its joint
cad.twin            every box backed, 1787.3 g sim = 1787.3 g cad
cad.fasteners       worst preload 1.30 deg, flips 8/8 at 4.3 deg
cad.wiring          worst change 9.4 mm
cad.assemble_check  57 solids, 1 connected group at 0.05 mm, both modes
                    0 interfering pairs, 0 of 34 running pairs close at
                    worst case, nothing collides through the flip
fitcheck.py         0 interpenetrating pairs in both modes and all 26
                    flip poses, 1 connected group in both
cad.linkage         every pivot made, every mount seated, rod2 13.0 mm off
                    the floor, nothing collides over 13 poses
cad.toolaccess      every screw reachable
cad.printability    every part printable
```

Nothing here floats and nothing here interpenetrates, at the solid level, which
is the level that gets printed.

### What the test suite then found, which was more than the checks did

Every fidelity check above was green before pytest ran. It came back with six
failures, and five of them were real.

**The thigh was two loose pieces.** The fork and the spine do not touch: the
spine stops at z = -74 and the fork starts at -63, and the real part bridges
them with a cross-member over the top of the servo that I had not drawn. Every
robot-wide check passed anyway, because the robot was still one connected group
through the knee servo. `tests/test_foot.py::test_every_body_is_one_rigid_piece`
is the only thing that asks whether the parts on ONE BODY touch each other, and
it is exactly the question a leg in two halves fails. Five boxes now.

**`cad.linkage.ground()` had quietly stopped measuring the yoke arm**, and read
5 mm better for it. That is written up as how-checks-fail #20. `mounts_placed()`
puts the three mount features back in front of it; the lowest part is the arm
again at 13.0 mm, control-tested by dropping its root 19 mm, which reads -4.5.

**The flip's cliff moved to 12 degrees**, measured over ten trigger times:

```
   4.3 deg  6/6       10 deg  4/10
   6   deg  5/6       12 deg  0/10
   8   deg  3/6       14 deg  0/10    16 deg  0/10
```

Ten had stopped being a cliff and had been failing quietly as a guard: a
six-trial sweep still reads 0/6 at ten, and the full ten reads 4/10 because the
last four trigger times survive. Twelve is 0/10 at both zero linkage damping and
the shipped value, and it is 2.8x the 4.3 degrees the robot is built to.

**The whole-robot mass literal went stale for the third time**, 1.799 against a
CAD that now builds 1.787, because the fin, stub and arm became host features.
It derives from `cad.masses.table()` now, same as test_stage0.

**The shin can no longer mesh at 2.2 mm.** The knee stub took it to 56 198
nodes, past `fea.MAX_NODES`; 2.15 is worse at 59 610 and 2.3 comes back with an
inverted element. The convergence test brackets 3.0 against **2.25**, which is
52 622 nodes and the same refinement in every way that matters. The ceiling was
not raised: this machine has 24 GB free and 65 000 nodes took 32 GB here once,
and took an unrelated application with it.

## Still open, unchanged in rank

1. Redraw the shin: 9.40 cm3 of mount for a servo that is not there, plus the
   forward carrier that only reaches y = 136 because the deleted belt forced
   the bearing out. Both together. The fin, stub and arm are now folded into
   their hosts, so that half is done.
2. The servo capture preload, 1.3 degrees, four parts.
3. Printed mass quoted at PETG's density for parts ordered in PA6-CF, ~26 g.
4. Backlash unmeasured on real hardware, which everything above is quoted
   against.
5. `cad.stress` has never solved a rod.

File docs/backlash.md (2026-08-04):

# Backlash

`load(backlash=radians)` builds the robot with gear lash. This was the last
thing that could still invalidate the design before spending money, and the
answer is: **it does not kill wheel mode, but it breaks foot mode.**

## How it is modelled

Physically, not as a command deadband. Every actuated joint gets a second
"lash" joint in series, free to float within +/- lash/2, with a small inertia
stub on the gearbox side:

    servo drives and senses  ->  [lash joint, free play]  ->  link

The servo commands and reads the proximal side; the link hangs off the distal
side and can move without the motor knowing. That floating deadzone in the
kinematic chain is what actually hurts a balancer. A deadband applied to the
command would not reproduce it, because the load could not move on its own.

All 10 joints get lash, including the wheel drive - an unloaded wheel that can
turn without the encoder seeing it is exactly what poisons the odometry.

`backlash=0` builds the rigid model with no extra bodies at all, so joint
indices are unchanged and every existing test still addresses the same model.

## A wrong turn worth recording

The first pass at this re-tuned the balancer against lash and reported that it
"survives up to 2 deg". That was wrong, and the cost function was why: falling
was penalised at 100+, oscillation at only 3x max_pitch. The search happily
returned a set that never fell and **limit-cycled at +/-16 deg with the lash
switched off entirely** - it had simply found a violent oscillation that stayed
upright. It looked fine in aggregate metrics and looked drunk on video.

The cost now weights steady-state pitch RMS and peak-to-peak heavily
(`pitch_rms * 60 + pitch_ptp * 30`, measured over the back half of a run), which
ranks that gain set at 130 against 15 for the rigid defaults. Lesson: "did not
fall" is not a fitness function.

## Results

Two changes fix it, and together they are worth more than any amount of gain
tuning.

**Much lower inner-loop gain.** Multi-start search, rather than coordinate
descent from the rigid optimum, lands at `kp` 10.4 instead of 48. A high-gain
loop through a deadzone chatters by construction.

**A low-pass on the wheel command** (`tau_cmd`, 80 ms). Slamming the command
across the deadzone is what drives the limit cycle, and filtering it is what
actually kills it: at 1 deg of lash the pitch swing drops from 17.7 deg
peak-to-peak to 0.9. Beyond ~150 ms the lag itself becomes the problem and at
250 ms the robot falls.

One gain set now covers both rigid and lashed:

    kp 10.435   kd 0.435   kv 0.300   kx 0.500   tau_odom 0.100   tau_cmd 0.08

| lash | quiet swing | max shove | drift 25 s | round trip |
|---|---|---|---|---|
| 0 | 0.1 deg pp | 1.4 N.s | 28 mm | ok |
| 0.5 deg | 0.1 deg pp | 1.4 N.s | 64 mm | ok |
| 1 deg | 0.9 deg pp | 1.4 N.s | 76 mm | ok |
| 2 deg | 9.9 deg pp | 1.4 N.s | 76 mm | ok |
| 3 deg | 29.6 deg pp | 1.0 N.s | 304 mm | ok |

The old `kp=48` set falls at 0.5 deg and every level above it. The new set is
identical to it on a rigid robot (same 1.4 N.s shove rejection, same quiet
pitch) and survives to 3 deg.

The one real cost is position hold: `kx` drops from 0.86 to 0.5, so standing
drift roughly doubles to about 28 mm over 60 s. Pushing `kx` back above 0.7
starts costing shove rejection.

## What this means for foot mode

**Foot mode was the real casualty, and this was the surprise.** The transition
itself completes - it reaches STAND at 8.79 s with 1 deg of lash - and then it
**falls over while standing still**. Passive static stability is precisely the
thing that depends on rigidity: lash across hip, knee and ankle lets the body
rotate 2-3 deg for free, which eats a third of the 9.1 deg tilt margin before
any servo can even feel it, and the robot builds momentum inside the deadzone.

So the headline claim from stage 0b - "stands with the controller completely
off" - is a rigid-model result. On real servos it needs a controller, just a
weak one.

## The fix that was: a low-gain ankle loop in foot mode

> **DELETED 2026-08-03, and the whole section is kept for the argument rather
> than the code.** There is no ankle servo any more, so there is nothing for a
> loop to drive: a passive parallelogram takes up the lash mechanically and
> does the job the loop could not. Foot mode stands **10/10 at 4 degrees**
> where this loop managed 2/10 at 2. See
> `docs/deleting-the-ankle-pitch-servo.md` and `cad/linkage.py`.
>
> What is worth keeping is the reasoning below, because it is what identified
> the problem correctly - something has to take up the lash before the body can
> rotate through it - and only got the solution wrong. A linkage cannot help
> doing that, instantly, with no gain to tune.

Foot mode no longer switches the controller fully off. It runs a weak
PID on ankle pitch against IMU pitch - the support polygon still does the
work, but *something* has to take up the lash:

    apitch += stand_kp * pitch + stand_kd * pitch_rate + integral
    stand_kp 1.2   stand_kd 0.12   stand_ki 0.6

Positive ankle pitch tips the toe down, and the reaction rotates the body
back, so a forward lean wants more ankle pitch. The integral absorbs the
steady offset from the CoM not sitting dead centre on the foot, which leaves
the P term free to fight disturbances.

> **SUPERSEDED, 2026-08-02. The table below no longer holds.** It was measured
> against the old inertia. `SEG_INERTIA` was regenerated from the CAD that day
> (1874.8 g to 1907.0 g, and the roll bracket's centre of mass moved 11.5 mm),
> and re-measured foot mode now stands **2/10 at 2 deg and 3/10 at 3 deg with
> the loop ON**, not reliably as recorded here.
>
> Correcting the mass distribution broke foot mode at the lash the servos
> actually have. See `docs/deleting-the-ankle-pitch-servo.md`, which measures a
> passive parallelogram standing 10/10 at both.
>
> **And then the mass moved again, favourably.** Deleting the ankle servo and
> its belt drive took 89 g off the end of each leg (1907 g to 1800), and the
> linkage now stands 10/10 at FOUR degrees, where the same linkage on the
> heavier robot failed four ten times out of ten. The cliff is between 4 and 5.

**Standing, 15 s:**

| lash | loop off | loop on |
|---|---|---|
| 0 | stands, 3.6 deg wobble | stands, **1.1 deg** |
| 0.5 deg | stands, 11.9 deg | stands, **3.1 deg** |
| 1 deg | stands, 13.8 deg | stands, **3.8 deg** |
| 2 deg | **falls at 1.1 s** | stands, **4.7 deg** |
| 3 deg | **falls at 1.0 s** | stands, **5.5 deg** |

**Largest shove survived:**

| lash | loop off | loop on |
|---|---|---|
| 0 | 0.4 N.s | 0.5 N.s |
| 1 deg | 0.2 N.s | **0.5 N.s** |
| 2 deg | falls unshoved | **0.5 N.s** |

Disturbance rejection becomes lash-independent, and 0.5 N.s is close to the
geometric ceiling - tipping over the 40 mm foot edge takes about 0.58 N.s of
energy, so there is little left to win without a bigger foot or a step.

**Full round trip** (drive, flip, stand, flip back, drive on):

| lash | loop off | loop on |
|---|---|---|
| 0.5 deg | ok | ok |
| 1 deg | **falls in STAND** | ok |
| 2 deg | **falls in STAND** | ok |

The gains sit right at the stability edge: anything above `stand_kp` 1.2
chatters through the deadzone and is unstable. Do not turn it up.

## Still to do about it

1. **Lash is still a purchasing spec.** Wheel mode is fine to 1 deg (0.9 deg of
   swing) and usable at 2 deg (9.9 deg), but 3 deg gives 30 deg of swing and
   300 mm of drift. Under about 1 deg, backlash stops mattering; over 2 deg it
   dominates everything.
2. **Re-tune on hardware.** `balance.LASH_GAINS` is a starting point tuned
   against a guessed lash figure, not an answer.
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

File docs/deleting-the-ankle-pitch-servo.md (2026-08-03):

# Deleting the ankle-pitch servo

> Ankle pitch does the least work of any joint in the robot and drags the worst
> subsystem in it. Can a passive parallelogram do the job instead?

Asked 2026-08-02. The answer is **yes, and it is not close**: with a linkage and
no ankle actuator at all, foot mode stands 10 out of 10 at the 2-3 degrees of
gear lash where the servo version now stands 2 or 3 out of 10.
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

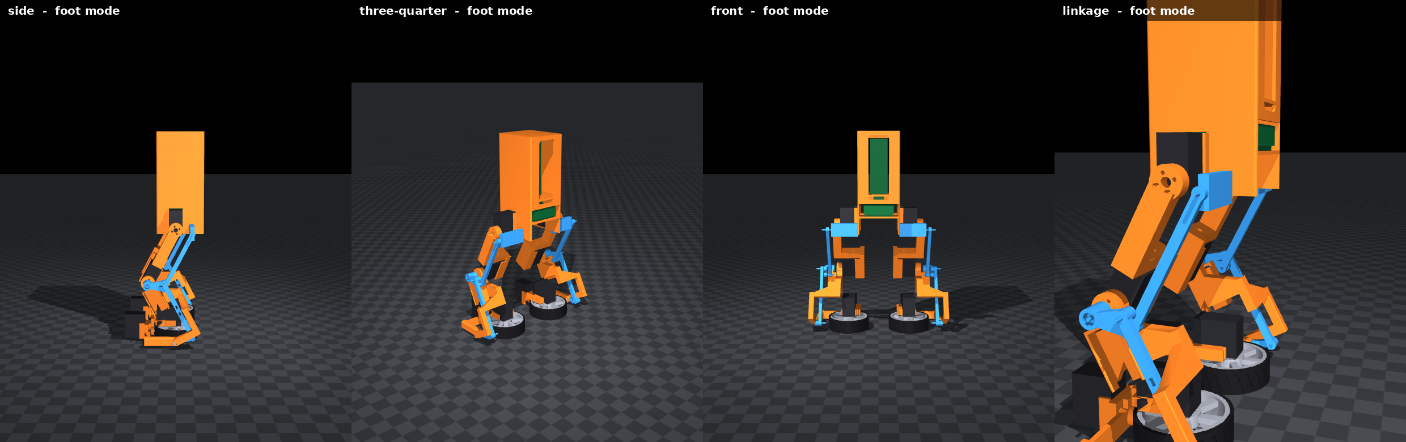
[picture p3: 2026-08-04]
renders/linkage_foot.png

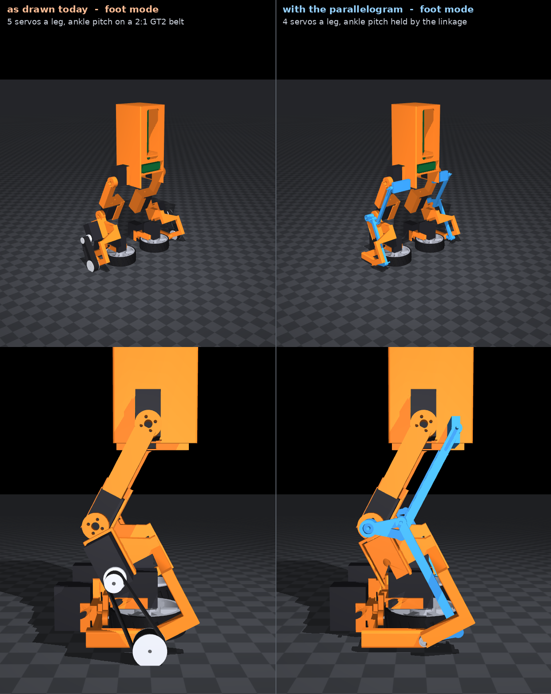
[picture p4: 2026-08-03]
renders/servos-before-after-foot.png

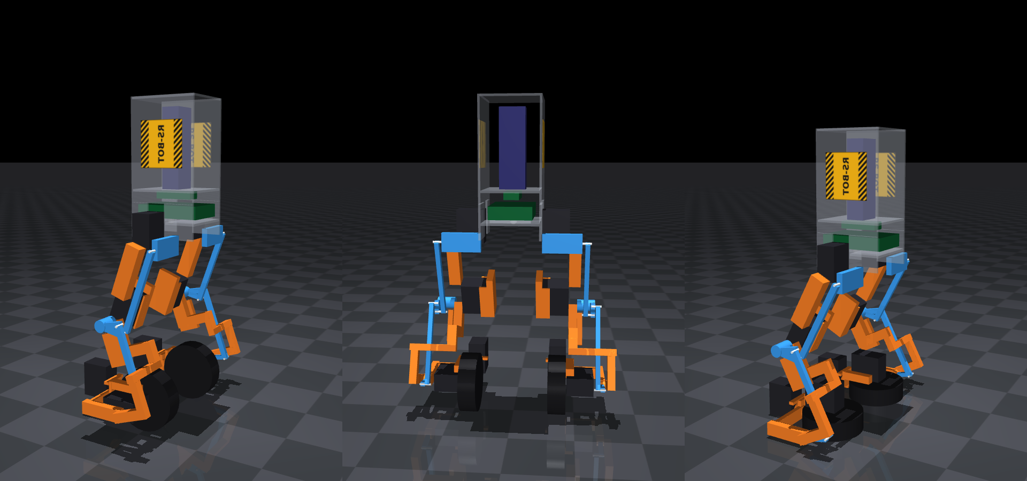
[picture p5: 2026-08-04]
renders/sim_linkage.png

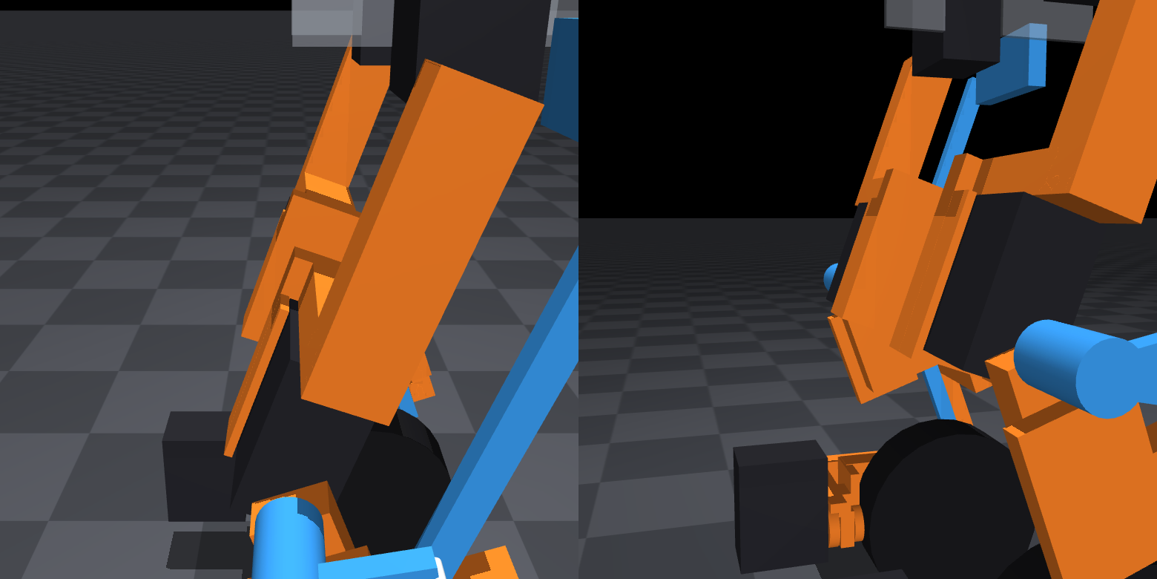
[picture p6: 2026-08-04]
renders/thigh-fork.png

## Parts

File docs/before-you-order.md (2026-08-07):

# Before you order anything

Read this first if you are picking up rs-bot. It says what the project is
actually trying to prove, what has been verified against reality and how, and
what is still fiction.

> **Current state, 2026-08-06 (this supersedes stale numbers further down).**
> The robot is **1749 g**, EIGHT servos, no belt and no ankle-pitch servo - a
> passive parallelogram replaced them - and PA6-CF throughout. Sim mass = CAD
> mass to the milligram. The body below still says 1.907 kg, ten servos, a belt,
> a 39.60 mm servo (it is 36.50 now), and "53 tests"; those are history. The
> verification suite is ~106 checks and green, and the linkage rod now has a
> real FEA behind it.
>
> **Two things below are no longer true and matter.** "Fasteners are specified"
> is only half right: the bolt list exists, but the **16 M2.5 heat-set insert
> bores it calls for are not modelled in any part** (found 2026-08-06), so the
> part-to-part joints have nowhere to seat an insert. And the order sheet's
> fastener rows are stale (40 deleted case screws; missing the horn centre screw
> and rod-clamp bolts). See `road-to-order.md` for both. Everything else still
> open is physical - material coupon, bore fits, backlash - and wants the $30
> validation order, not more simulation.

## The mission

Prove that a simulator plus an agentic AI can do the whole loop - CAD, physics,
control, verification - well enough that the hardware works **first time**.

That last part is the whole point. The operator gets **one order**. So the
question is never "does it look right", it is **"what in this model is still a
number somebody made up?"** Every section below exists because the answer was
once "quite a lot".

## The one rule this project runs on

> A check that cannot fail is worse than no check at all, because it reads as
> evidence.

Every significant fault here was found by a check that was *made able to fail*,
and several were hidden for weeks by checks that could not be. Before trusting
any check you add, break the thing it tests on purpose and confirm it screams.

Examples, all real:

| check | how it was silently passing |
|---|---|
| whole-robot interference | MuJoCo skips collision between static world children - it reported clean with a part shoved 100 mm into the robot |
| chassis stress | held nodes and loaded nodes were the same set, so nothing could move: 0.00 MPa |
| fit checker | skipped same-body pairs as lap joints, hiding a bracket 2597 mm3 inside a servo case |
| tuning cost | penalised falling at 100 and oscillation at 3, so it returned gains that never fell and limit-cycled at +/-16 deg |
| tuning cost, again | had no yaw input at all, so a set of gains limit-cycled at +/-2 rad/s and walked a metre backwards while scoring well |
| FEA solve | SuperLU diverged silently - same geometry and load, 22.7 MPa in one material and 132.8 in another |

## What is verified, and against what

| | how | status |
|---|---|---|
| Geometry, both modes and through the flip | boolean intersection of 19 real solids, plus an OBB sweep over 26 poses | clean |
| Every body is one rigid piece | connectivity with a tolerance tight enough to catch a gap inside a part | clean |
| Nothing touches the floor in foot mode | support-point check, both modes | clean |
| Loads | `d.cfrc_int` off the sim - exact, inertial and contact terms included | closes against statics, 6.12 N vs 6.12 N |
| Stress | TET10 FEA, `cad/fea.py` | cantilever benchmark: +1.9% deflection, +3.1% stress |
| Mass and inertia | composed from real B-rep solids plus bought-part boxes | mass closes against `cad/masses.py`; tensors positive definite |
| Printability | overhang, wall thickness, bed footprint | all five parts fit, no sub-1.2 mm features |
| Servo torque | measured over the whole envelope | duty above continuous 0-1.9% |
| Balance, transition, backlash to 2 deg | 53 tests | passing |
| **Servo dimensions** | **measured off a real STEP model** | see below |

### The servo is the one that mattered

Every servo dimension was invented from a product listing. Four of the five
printed parts bolt to a servo, so those numbers set every mounting face in the
robot. `cad/servo.py` now reads them from TheRobotStudio's SO-ARM100 STEP:

| | assumed | real |
|---|---|---|
| case height | 35.4 | **39.60 mm** - and it is along the OUTPUT SHAFT |
| horn bolts | r = 8.0 at 45 deg | **9.9 x 10.0 rectangle** - every hole 0.71 mm out |
| horn screw | M2 | 2.5 mm clearance |

Applying it removed 4.2 mm of clearance that never existed and broke **16
clearance pairs**. Fixing them moved the shin's whole outboard route, the
chassis shelves, the ankle servo and the yoke. Nothing about that was visible
before the real number arrived.

**The lesson for whoever is next: a bought part's dimensions are not a
detail, they are the boundary conditions of every part that touches them. Get
the real CAD before drawing anything against it.**

## What is still fiction

Most of the original list has been closed. What is left is what CAD cannot
answer.

1. **The servo horn bolt pattern is assumed.** The horn is a bought part and
   its pattern is not in the servo STEP, so it was never measured, and four of
   the five printed parts bolt to a horn. There is a decoy in that file: the
   case has four screws at each end on a 9.9 x 9.9 rectangle, almost exactly
   what this project believes the horn to be. This is now the single most
   load-bearing assumption in the robot.
2. **The servo case mounting positions are assumed**, same reason. What IS
   verified is that every servo hole runs along the shaft axis and that all 28
   holes in the printed parts agree with it.
3. **There is no central horn screw in the CAD.** A horn is fixed to its spline
   by an axial screw; nothing models it or checks access to it, and it is the
   only screw actually fitted on the robot at a horn joint.
4. **Bearing bores are nominal.** A printed bore needs measuring and
   offsetting, usually 0.1-0.2 mm. So does the 0.35 mm tyre press fit.
5. **Cable channels do not exist.** The runs are modelled now
   (`cad/wiring.py`) and three of them pass through printed structure, so the
   thigh, shin and yoke need channels cut before they are ordered.
6. **Material and fatigue properties are published figures**, not coupons off
   the machine that will make these parts. Expect +/- 20%.

Closed since this list was written: fasteners are specified
(`cad/fasteners.py`), tool access is checked in build order
(`cad/toolaccess.py`), tolerance is stacked along the chain rather than
pair-by-pair, mesh convergence is run on the two parts near their limit and
both have settled, and fatigue is solved on the flip at 1x with PA6-CF passing
everything at 70% worst.

## What to buy, and what not to

**Printed parts USED to be treated as not the risk**, on the grounds that you
can reprint a bracket for pennies. That is false here: the operator has no
printer, so every part comes from a service and a reprint is real money and one
to two weeks. Printed-part correctness now matters about as much as bought-part
correctness, and `road-to-order.md` re-ranks the remaining work on that basis.

The bought parts are still where the irreversible spend is:

| | decision | why |
|---|---|---|
| Servos | 10x Feetech STS3215 | torque verified over the envelope; duty cycle fine, peaks saturate for milliseconds |
| Belt | **GT2 94T (188 mm), 15 mm wide** | centre distance falls on a stock size to a tenth of a tooth. 9 mm is over-tensioned at 132% |
| Pulleys | GT2 20T and 40T | 2:1 is pinned from both sides - below it the belt is overloaded, above it the servo runs out of travel |
| Bearings | 623ZZ | 3 mm shafts throughout |
| Wheels | **print them** | no commercial wheel has a usable side face, and this one is also the foot. Pololu's 25T range tops out at 90x10 |
| Material | **PA6-CF** | it is the only one that passes every part. ABS fails the shin and the roll bracket |

## Run these before believing anything

```bash
uv run python -m pytest tests -q     # 53 checks, ~80 s
uv run python fitcheck.py            # overlap, connectivity, flip sweep
uv run python -m cad.assemble_check  # real solids, every pair, both modes
uv run python -m cad.envelope        # where a feature is allowed to go
uv run python -m cad.stress          # FEA, every part, every material
uv run python -m cad.printability    # overhangs, walls, bed
uv run python -m cad.loads           # joint loads, with its statics control test
uv run python -m cad.servo           # the measured servo, vs what was assumed
uv run python -m cad.fasteners       # the bolt list, and do the screws line up
uv run python -m cad.toolaccess      # can a driver reach every screw
uv run python -m cad.wiring          # where the cables go, and how much slack
uv run python serve.py               # drive it, localhost:8781
```

`cad/envelope.py` is the one to reach for when adding geometry: it holds the
forbidden volumes as solids, so you intersect against them instead of
reasoning about them. It is deliberately conservative - it sweeps roll and
pitch independently, so a small overlap there may still be fine on the real
trajectory. `fitcheck.py` and `cad/assemble_check.py` settle that, because they
sweep the manoeuvre the robot actually performs.

## Where it stands

**1.907 kg**, every gram derived from geometry rather than assigned. It read
1.858 until 2026-08-02: five servo cradles and a closed chassis, none of which
had reached this page.

The robot balances, drives, steers, flips both ways, and survives 2 deg of gear
lash against a measured 0.87 in the real servo.

**It is not ready to order, and the fix is cheap.** Buy ONE servo and one horn
first. That settles items 1, 2 and 3 - the whole top of the list - plus the
printed bore tolerance, for the price of a coffee and a week. See
`road-to-order.md` and `order-sheet.md`.

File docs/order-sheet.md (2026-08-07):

# The order sheet

Everything you have to buy or have made, with a quantity against every line.
Someone who is not you should be able to place this order without asking a
question.

`bom.md` is the reasoning: what the parts are, why the servos sit where they
sit, and what modelling them at real size revealed. This is the shopping list.

**Read `road-to-order.md` before spending anything.** Three lines here are still
unverified and one servo will settle all three.

> **BLOCKING, 2026-08-03: three linkage pieces are drawn as separate parts and
> belong to other parts.** `lk_fin` is chassis, `lk_stub` is shin, `lk_arm` is
> ankle yoke. Until they are cut into their hosts, this sheet describes a robot
> that cannot be assembled, and the shin should shrink when it happens - its
> outboard carrier only reaches y = 136 because the deleted belt forced the
> ankle bearing out there.

---

## 1. Printed parts

All from a service. **PA6-CF, FDM**, from Unionfab or Weerg: it is the only
material that passes every part, and `materials.md` has the numbers plus the
reason the obvious vendors (JLCPCB, PCBWay) do not work.

Files are written into `cad/out/` by `uv run python -m cad.robot`.

| file | qty | material | mass ea |
|---|---|---|---|
| `chassis.step` | 1 | PA6-CF | 135 g |
| `thigh.step` | 2 | PA6-CF | 41 g |
| `shin.step` | 2 | PA6-CF | 40 g |
| `ankle_yoke.step` | 2 | PA6-CF | 14 g |
| `roll_bracket.step` | 2 | PA6-CF | 8 g |
| `wheel_body.step` | 2 | PA6-CF | 27 g |
| `wheel_tyre.step` | 2 | **TPU 95A** | 27 g |
| `lk_rod1.step` | 2 | PA6-CF | 7 g |
| `lk_rod2.step` | 2 | PA6-CF | 7 g |
| `lk_idler.step` | 2 | PA6-CF | 4 g |

> **THREE MORE LINKAGE PIECES ARE NOT ON THIS LIST AND THAT IS WHY YOU CANNOT
> ORDER YET.** `lk_fin` (12 g), `lk_stub` (3 g) and `lk_arm` (2 g) are FEATURES
> of the chassis, the shin and the ankle yoke, drawn separately in
> cad/linkage.py and not yet cut into their hosts. Ordering today would buy
> three loose pieces with nothing to bolt them to. See the blocking list below.
>
> `lk_rod2` is also drawn as one piece and specified as two, clamped, because
> its length has to be adjustable at assembly. cad/linkage.py's ADJUST_MM says
> why and tests/test_linkage.py measures what happens without it.

Right-hand parts are the left mirrored in y, except the two wheels, which are
the **same part flipped over**. One part number, print two.

**Specify 60% infill or better.** The entire strength study assumes it and
service FDM often defaults far lower. That is a line on the order form, not an
assumption you get to make afterwards.

**Cost: get a real quote, because this is the line nobody can estimate.**
19 physical pieces, 430 g of PA6-CF plus 53 g of TPU.

> The 183 g this line used to claim was the LEGS ONLY, quoted as if it were the
> robot, with the 135 g chassis never in it. It is in `docs/how-checks-fail.md`
> as entry 7. The figure above is `uv run python -m cad.masses` summed over the
> printed column, which is where it should have come from all along.
>
> **It is computed at PETG's 1.27 g/cm3 and these parts are ordered in PA6-CF
> at 1.19.** That is about 26 g the model is carrying that the robot will not
> be, and it is not fixed here because the material is not settled: three PA12
> variants came back into play when the roll bracket went from 99% to 55%
> (`road-to-order.md` item 8), and the density follows the material. Service FDM in PA6-CF
prices per part rather than per gram, with a setup charge that dominates on
small parts like the 6 g roll bracket, so expect somewhere between **$180 and
$420** and treat any single number as fiction until Unionfab or Weerg have
quoted the actual STEP files. This is plausibly the largest line on the whole
order, larger than the servos. Upload `cad/out/*.step` and find out before
planning around the total below.

## 2. Bought parts

Prices are USD, checked 2026-07-28. **`v` was verified against a live listing
that day; `e` is an estimate and wants checking before you rely on the total.**
Nobody should be surprised at the checkout page.

| part | qty | unit | total | src | note |
|---|---|---|---|---|---|
| **Feetech STS3215-C018** (12 V, 1:345) | 8 | $16.00 | $128 | v | EIGHT, not ten: see the note below |
| 25T **metal** servo horn | 8 | $2.50 | $20 | e | pattern measured, see `cad/servo.py`. Metal, not the POM horn that may ship in the box |
| 623ZZ bearing, 3 x 10 x 4 | 6 | $1.00 | $6 | e | ankle pitch and the linkage idler, both legs. Sold in 10-packs |
| 3 mm shaft, 30 mm | 4 | $1.00 | $4 | e | ankle pitch and ankle roll. Or cut from stock |
| 3 mm pin, 18 mm | 8 | $0.50 | $4 | e | the parallelogram's four pivots a leg. Cut from the same stock |
| Raspberry Pi 5 | 1 | $80.00 | $80 | e | 8 GB |
| 3S LiPo, 2200 mAh | 1 | $25.00 | $25 | e | |
| TTL bus adapter, FE-URT-1 class | 1 | $10.00 | $10 | e | needed for the validation order too, buy it early |
| IMU, BNO085 class | 1 | $25.00 | $25 | e | breakout board |
| Servo bus cable, 3-pin, 100 mm | 4 | $1.50 | $6 | e | |
| Servo bus cable, 3-pin, 150 mm | 4 | $1.50 | $6 | e | hip and roll joint, which need slack. `cad.wiring` now wants a 9 mm service loop, up from 6 |
| | | | **$314** | | |

> **TWO SERVOS AND A WHOLE BELT DRIVE CAME OFF THIS LIST.** $81 of parts
> deleted against $6 added, so $78 net, and 178 g out against 70 g of linkage
> back in, so 107 g net. The ankle-pitch servo is replaced by a passive parallelogram: see
> `docs/deleting-the-ankle-pitch-servo.md`, and `cad/linkage.py` for the
> mechanism. Gone with it: two 25T horns, a 20T GT2 pulley on a 4.40 mm hub
> that was not a catalogue part, a 40T pulley that sat 2.23 mm below the floor
> in foot mode, and a 188 mm x **15 mm** belt whose width this sheet flagged as
> uncommon and possibly needing a specialist. That sourcing risk is gone.

**Order by part number, not by name.** Feetech sells at least five STS3215
variants that look identical in photographs and are not interchangeable:

| part | V | torque | ratio | |
|---|---|---|---|---|
| **C018** | **12** | **30 kg.cm** | **1/345** | **this robot** |
| C001 | 7.4 | 19.5 kg.cm | 1/345 | |
| C044 | 7.4 | 16-27 kg.cm | 1/191 | |
| C046 | 7.4 | 14.4 kg.cm | 1/147 | |

Most listings that surface first are the 7.4 V ones, because those are what
SO-ARM100/101 uses. Searching `STS3215 C018` filters correctly in one step.
$16 is OpenELAB's price; Amazon runs about $24.50 a unit for next-day.

The belt is 15 mm and not 9 because the measured joint peak is 132 N of
tension, and the 2:1 ratio is pinned from both sides: below it the belt is
overloaded, above it the servo runs out of travel.

## 3. Fasteners

> **The fastener interface is now consistent end to end (2026-08-06).** This
> table had drifted from the CAD - 40 deleted M2 case screws, missing the M3x6
> horn and rod-clamp bolts, and 16 inserts with no bore to seat in - and every
> one is fixed. The count is **8 inserts, not 16**: the 8 "chassis side plates ->
> top" were for a joint a one-piece chassis does not have and came off. All 8
> real insert bores are cut (4 in the chassis Pi standoffs, 4 in the ankle
> yokes), so `cad.fasteners inserts_seated` reads empty. The **material** is
> still the block: PA6-CF strength on a coupon, not the order sheet's job. See
> `road-to-order.md`.
>
> The list below is the true output of `uv run python -m cad.fasteners`
> (`fastener_order()`), and a test holds it there. Regenerate, do not hand-edit.

| part | qty |
|---|---|
| M3 x 8 socket cap | 32 |
| M3 x 6 socket cap (horn centre screw) | 8 |
| M3 x 12 socket cap (rod-2 clamp) | 4 |
| M3 nut, captive (rod-2 clamp) | 4 |
| M2.5 x 8 socket cap | 4 |
| M2.5 x 6 socket cap | 4 |
| M2.5 heat-set insert, 3.5 mm bore x 4.0 deep | 8 |

Buy 25% spares. They cost nothing and one missing screw stops a build for a week.

### What threads into what

| interface | screw | threads into |
|---|---|---|
| part to servo **case** | M2 self-tapping | the servo's own 1.5 mm pilot |
| part to servo **horn** | **M3** | the horn, which is metal and tapped |
| part to part | M2.5 | a heat-set insert |

The horn screw is M3 and not M2.5, and that is measured rather than assumed:
TheRobotStudio's own SO-ARM101 parts carry 3.0-3.2 mm clearance holes on the
horn pattern. A clearance hole in the plastic means the thread is in the horn,
so a horn joint needs **no insert** - which is why the insert count fell from
48 to 16.

Inserts for anything taken apart more than twice, which is every servo mount on
a robot that has not been built yet.

## 4. Tools

| tool | ~cost | why |
|---|---|---|
| 2 mm hex key, short | $8 | four of the thigh's screws will not take a full-size driver's handle. `cad/toolaccess.py` found that, rather than the bench |
| soldering iron with M2.5 insert tip | $15 | 16 inserts |
| **digital calipers, 150 mm, 0.01 mm** | $40 | the validation order is worthless without them. Do not buy the $25 tier: the headline check is a Ø19.95 horn in a Ø20.00 pocket, and at 0.05 mm a cheap caliper measures itself |
| pin gauges or drill bits | $0-25 | calipers cannot measure hole **positions**, and the case mounting pattern is exactly that. Pin the holes, measure over the pins, subtract one pin diameter |

A flatbed scanner, if you own one, beats all of the above for the case pattern:
1200 dpi is 0.021 mm per pixel and it captures the whole 2D pattern at once
instead of pair by pair.

## 5. Cable channels: cut, with one exception

The thigh, shin and ankle yoke now carry a 6 mm channel along the cable run,
cut for BOTH poses because the paths move between them. Wheel mode is clear on
all eight runs; foot mode has one left.

**The roll-to-wheel run is not solved and cannot be by a channel.** It crosses
the ankle roll joint, so its far end is on a bracket that turns 90 degrees, and
its shortest path passes through the WHEEL in foot mode. You cannot groove a
part that spins. That run needs a routed path tucked inboard of the wheel, held
by a clip, taking up the 6.3 mm of length change as a service loop with an
8 mm bend radius.

Decide that route before ordering: it may want a tie point on the yoke, and a
tie point is a printed feature.

---

## 6. What the whole thing costs

Added 2026-07-28. Before this, `bom.md` promised that "the quantities and prices
live in the order sheet" and only the quantities did.

| line | low | high | confidence |
|---|---|---|---|
| Printed parts, PA6-CF + TPU | $180 | $420 | **needs a real quote** |
| Bought parts | $314 | $314 | servos verified, rest estimated |
| Fasteners and inserts, incl. 25% spares | $40 | $40 | estimated |
| **Build subtotal** | **$534** | **$774** | |
| Tools, one-time | $63 | $88 | estimated |
| **Total** | **$597** | **$862** | |

Three things worth reading off that table:

- **The printed parts cost more than the servos**, and by more than they used
  to: the servo line is down to $128 and the printed mass is up to 431 g. Until the STEP
  files are quoted, the largest number here is the one nobody has priced.
- **Buying the servos on Amazon adds about $85** to the total ($24.50 against
  $16 a unit) for next-day delivery. Worth it for the validation order,
  wasteful for the other eight.
- **This is cheap for what it is.** A single Dynamixel XL430 is around $50 and
  a DIY QDD actuator is $150+, which is why the whole LeRobot ecosystem
  standardised on this servo. See the 2026-07-28 status report for why building
  custom actuators was considered and rejected.

## Do not order all of this at once

`road-to-order.md` argues for a validation order first: **about $60 in parts,
or $100 including the calipers you do not yet own.** These are the reasons, in
order of what they would cost to get wrong:

1. ~~The horn bolt pattern is assumed.~~ **Now measured** off three
   TheRobotStudio SO-ARM101 parts that bolt to the same horn, six patterns
   agreeing to 0.00 mm. It moved the screw from M2.5 to M3 and grew every horn
   hole in this robot by 0.7 mm.
2. **The servo case mounting positions are still assumed.** What is verified is
   that every servo hole runs along the shaft axis and that all 36 holes in the
   printed parts agree with it.
3. **There is no central horn screw anywhere in the CAD.** A horn is fixed to
   its spline by an axial screw. Nothing models it, sizes it, or checks you can
   reach it, and it is the *only* screw actually fitted on the robot at a horn
   joint, because the four pattern screws are done on the bench.
4. ~~Cable channels do not exist.~~ **Cut**, in the thigh, shin and ankle yoke,
   for both poses. One run is left and it needs a ROUTE rather than a groove:
   roll-to-wheel passes through the wheel in foot mode, and you cannot channel
   a part that spins. It wants a clip and a tie point, and a tie point is a
   printed feature - so decide it before ordering.

**Buy two servos, a metal horn and a bus adapter first.** About $60, and a
week. It settles 2 and 3, plus the printed bore tolerance and the 0.35 mm tyre
press fit.

**Two, not one, and the reason is the same one that recovered the horn.** A
single servo gives you a *measurement* of the case mounting pattern. Two give
you a *check*: if both agree, the pattern is real, and if they disagree, that
disagreement is the finding, which matters a great deal when the plan is to put
40 M2 screws into those holes. Agreement between independent parts is the
measuring instrument here, exactly as it was for the horn.

The adapter is on the list because backlash is an angle, not a length: command
the servo to hold, twist the output by hand, read the position back. The 12-bit
encoder resolves 0.088 deg, so it measures 2-3 deg of lash easily and no
caliper can.

## Mass, for the record

**1.749 kg**, and every line below is `uv run python -m cad.masses`, summed,
rather than a number carried forward from the last time someone wrote this out:

| | g |
|---|---|
| printed structure, all nine parts | 359 |
| servos, 8 x STS3215 | 440 |
| arm/head ballast + IMU (stage 4 stand-in) | 605 |
| torso electronics: Pi 5, 3S pack, bus adapter | 235 |
| wheels, 2 x (printed body + TPU tyre + horn) | 110 |
| **total** | **1749** |

1907 to 1770 in two steps, both on real deletions. The ankle-pitch servos and
their belt drive came out on 2026-08-03 when the parallelogram went in, which
is 10 servos to 8 and the whole belt line gone; the rods and idler that replace
them are 34 g of the printed total. Then on 2026-08-04 the shin gave up the
mount for the servo that had already left - 53.05 cm3 to 45.11, about 9 g a leg.
The 1 g back on 2026-08-05 is the seating faces that stop the four floating
servos: an end wall under each hip servo and a datum wall on each roll cradle.

Also on 2026-08-05, 22 g came off on paper without a part changing: the printed
structure had been quoted at PETG's 1.270 g/cm3 - what it was costed in - while
it is ORDERED in PA6-CF at 1.19 (docs/materials.md). The density now lives in
one file, cad/material.py, that the CAD and the sim both import. The balancer
still stands 60 s and rejects a 1.0 N.s shove at the lighter mass.

It said 1.875 kg until 2026-08-02, which was the SIM's number, and the sim had
not been told about the cradles. The figure above is the CAD's, because the CAD
is what gets printed and this is the sheet you order from.

The printed line said **183 g** for weeks and was briefly "corrected" to 197 g
on 2026-08-02 by adding the cradles to the stale figure instead of re-deriving
it. It is 341 g. Incrementing a number you have not checked carries its error
forward and puts your name on it, and it happened here in the one file where
being wrong costs money.

> **The sim still says 1.875 kg.** `cad.twin` fails on that gap, per body, and
> it is open on purpose: closing it changes what the balancer was tuned
> against. It does not affect anything you would buy, which is why this sheet
> can be correct while that stays open.

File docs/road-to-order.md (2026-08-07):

# The road to ordering

> **2026-08-06: the digital work is nearly done, and the last gap it found is a
> real one.** State today: **1749 g**, EIGHT servos, the ankle-pitch servos and
> their belt gone (passive parallelogram), PA6-CF throughout, sim = CAD to the
> milligram. The verification layer is comprehensive and green - floating parts,
> servo seating, mass basis, interference through the flip, printability, the
> linkage rod's buckling AND eye stress are all settled. Most of the body of
> this file below is history; the numbers in it (1907 g, PETG, ten servos, the
> belt) are superseded.
>
> **The concrete blocker now is a paper-vs-geometry gap in the fasteners, found
> 2026-08-06.** The bolt list on `order-sheet.md` and in `cad/fasteners.py`'s
> SCHEDULE calls for **16 M2.5 heat-set inserts** - but the 3.5 mm bores they
> need are **not modelled in any part**. `M25_INSERT_R` is defined and used
> nowhere (a dead constant); where the schedule says "insert in chassis" the
> chassis cuts a 2.7 mm clearance hole straight through. So every PART-TO-PART
> joint (chassis assembly, Pi mount, ankle-pitch shaft retention) has no thread
> and nowhere to seat its insert. Print today and it stops at assembly. The
> order sheet's fastener rows are also stale the other way: 40 M2 case screws
> that were deleted with the capture cradles, and missing the 8 M3x6 horn centre
> screws and 4 M3x12 + 4 nuts the rod clamp needs. `fasteners.audit()` only
> verifies servo-screw ALIGNMENT (the horn holes, which do exist) and `bom()`
> counts inserts off the hand-written schedule without asking the geometry.
>
> **The checks are now in (2026-08-06).** `fasteners.inserts_seated()` asks the
> geometry for a 3.5 mm bore per scheduled insert and reports the shortfall
> (chassis 12, yoke 2), pinned in `tests/test_fasteners.py` the way the floating
> servos were; `fastener_order()` plus a test hold `order-sheet.md`'s fastener
> table equal to the schedule, so it cannot drift again. Both control-tested: the
> insert check detects a real blind bore and ignores a clearance hole.
>
> **CLOSED 2026-08-06: `inserts_seated` reads empty.** Cutting the bores split
> three ways. The 4 Pi standoff bores are in (the standoff top now takes an
> insert instead of the 2.7 mm through-hole that matched no fastener). The 8
> "side plates -> top" inserts were dropped - the chassis is one fused 193 mm
> print, so the joint and its 8 inserts + 8 M2.5x10 screws did not exist; the
> order is 8 inserts, not 16. The 4 yoke inserts are placed: two radial M2.5 set
> screws per pair retain the ankle-pitch shaft from the boss's exposed +x face.
> All of it verified - interference clean through the flip, meshes manifold,
> sim = cad at 1748.9 g.
>
> **One check earned an extension doing it.** `toolaccess` flagged the new insert
> bores as unreachable, because it treated them as screwdriver-driven screws.
> They are not: a heat-set insert is pressed with an iron before assembly and
> its screw comes from the mating part - the same bench-operation exclusion the
> horn screws already had. It now knows that, and its control test (a slab
> across a real driver path) still fails as it should. NOT covered, and named in
> the check: the yoke set screws are driven in the assembled robot with a hex
> key; that access measured ~2 mm clear but is not separately asserted.
>
> **Everything left after that is physical, and needs the $30 validation order**
> below: real PA6-CF strength (the roll bracket sits near its limit on LITERATURE
> properties), the bore and tyre press fits, and gear backlash. No amount of
> simulation produces those. The model has taken this as far as a model can.

> **2026-08-03: the ankle-pitch servos and their belt drive are deleted.** A
> passive parallelogram replaces them (`cad/linkage.py`,
> `docs/deleting-the-ankle-pitch-servo.md`). Ten servos to eight, 1907 g to
> 1800, $78 off the bought-parts line, and one sourcing risk gone with the
> 15 mm belt. The order sheet is updated and now BLOCKS on a new item: three
> linkage pieces are drawn as separate parts and belong to the chassis, the
> shin and the ankle yoke.
>
> **NEW, and it outranks everything below: the servo case mounting is not
> just unverified, it may be the wrong idea.** 40 of this robot's screws go
> into holes in the servo case. TheRobotStudio's own holder, which is the
> reference design for this servo, does not use those holes at all - it is a
> cradle that captures the servo in a cavity. That is why the pattern cannot be
> recovered the way the horn's was: a mating dimension gets encoded exactly by
> everyone who mates with it, and nobody mates with these. See `cad/servo.py`.
>
> **Investigated, and the answer is: capture is right, but it is a redesign,
> not a feature.** There IS room - 3 to 4 mm free at the hip, knee and ankle
> mounts, and the roll and wheel servos are already enclosed on three or four
> faces. But a rim will not attach: tried on the shin at both ends of the servo
> and at 6, 10 and 16 mm depth, it fuses as a separate floating solid every
> time. Every servo mount in this robot is a PLATE on the case's end face with
> no material anywhere around the case perimeter, so there is nothing for a rim
> to grow from.
>
> `cad.servo.cradle()` exists and its geometry is right; it is deliberately not
> wired in. Doing this properly means changing how four parts meet their
> servos, with packaging re-checked each time. Decide it BEFORE printing.
>
> **Cable channels are cut** in the thigh, shin and ankle yoke, for BOTH poses,
> because the runs move between them. Wheel mode is clear on all eight; foot
> mode has one left, and it needs a ROUTE rather than a groove: roll-to-wheel
> passes through the WHEEL in foot mode, and you cannot channel a part that
> spins. It wants a path tucked inboard with a clip, taking up the 6.3 mm of
> length change as a service loop.
>
> **Status, 2026-07-27: items 1 to 7 are all done.** What each one found is
> recorded in place below. The conclusion did not change: do not order all of
> it at once. Buy one servo and one horn first, because the three things CAD
> cannot settle all live on that interface.

What is left between here and placing an order, ranked by what actually stops a
build. Written 2026-07-27, after the wheel, clearance and assembled-strength
work landed.

Read `before-you-order.md` for what has been verified and against what. This
document is the other half: what has NOT been, and in what order to fix it.

---

## First, a correction to how this project ranks risk

`before-you-order.md` says:

> **Printed parts are not the risk.** You can reprint a bracket for pennies.
> The irreversible spend is the bought parts, so that is where the checking
> went.

That was written for someone with a printer on the desk. **The operator does
not have one.** Every printed part comes from a service, so a reprint is real
money and one to two weeks, and a reprint of something already built around is
worse than that.

So the sentence is false here, and it has been quietly steering where the
effort goes. Corrected:

| | with a printer | with a print service |
|---|---|---|
| reprint a bracket | pennies, same day | ~$20-40, 1-2 weeks |
| wrong hole diameter | reprint, lose an hour | reprint, lose a fortnight |
| discover it at assembly | annoying | the build stops |

**Printed-part correctness now matters roughly as much as bought-part
correctness.** Everything below is ranked on that basis, which is not the
basis the earlier work used.

---

## The strategy: order twice, not once

The stated mission is that hardware works first time, off one order. The way
to actually achieve that is **two orders, not one**:

1. **A validation order, roughly $30.** One printed coupon set plus the two or
   three cheapest bought parts. Its only job is to turn measured-nowhere
   numbers into measured numbers.
2. **The real order**, placed against corrected geometry.

This is not a retreat from the goal. Four of the seven items on the fiction
list are *material and process properties*, and no amount of simulation
produces them. They can only be measured off a part that exists. Spending $30
to stop guessing is the cheapest risk reduction available, and it is far
cheaper than reprinting the structure.

What the validation order answers:

| unknown | how the coupon answers it |
|---|---|
| bearing bore tolerance | print a bore, measure it, offset the CAD |
| the 0.35 mm tyre press fit | print a rim section and a tyre section, push them together |
| material properties | a tensile coupon in the real material, on the real machine |
| service DFM | the vendor's own automated checks run on the real STLs |
| real cost | the quote, which nobody in this repo knows |

---

## The work, ranked

### 1. There is no order sheet

**Status: blocking. `docs/bom.md` cannot be ordered from.**

It predates the CAD port and most of what has been learned since:

| line | says | reality |
|---|---|---|
| servo | 45.2 x 24.7 x 35.4 | 45.23 x 24.73 x **36.50**, the manufacturer's drawing |
| wheel | bought, 80 x 24, 60 g, ~$8 | **printed**, two parts, 54 g |
| structure | "Printed PETG ~400 g" | **197 g of PA6-CF** |
| total | 2.05 kg | **1.907 kg** |

And it is missing entirely: **fasteners, bearings, the belt and pulleys,
shafts, and cables.** Those are most of the part count.

**Exit criterion.** A table where every row has a specific part, a quantity, a
supplier and a price, and every printed part has a file, a material and a
process. Someone who is not you can place the order from it without asking a
question.

**Why it is first.** Not because it is hard, but because writing it forces
every remaining decision to be made explicitly. You cannot fill in a fastener
row without deciding item 2.

---

### 2. Fasteners: undecided, and it is a CAD change

**Status: blocking, and it is #1 on the project's own fiction list.**

Heat-set inserts versus self-tapping screws is not a shopping preference. The
two need **different hole diameters and different boss wall thickness**:

- a heat-set insert for M2.5 wants roughly a 3.5 mm bore and enough wall around
  it to take the melt without bulging
- a self-tapping screw wants a smaller pilot, sized to the screw's core
  diameter and the material

Nothing in `cad/` currently models either. Decide this after printing and every
part with a threaded interface is scrap.

There is a second question hiding behind it: **the robot has never been given a
bolt list.** How many M2, in what lengths, where. Every bolt hole in the CAD is
a clearance hole into air right now.

**Exit criterion.** Every fastener in the robot appears in a table with
size, length, type and count; every corresponding hole in the CAD matches that
choice; and a check exists that fails if a hole diameter and its fastener
disagree.

**Rule of thumb worth writing down:** inserts for anything taken apart more
than twice. That is every servo mount.

---

### 3. Tool access: nothing checks a driver can reach a bolt

**Status: unchecked, and this design is dense enough that it matters.**

Three servos live within 45 mm of one axle. The ankle yoke, roll bracket and
wheel all crowd the same 60 mm. Nothing anywhere verifies that a screwdriver,
hex key or nut driver can physically reach each fastener, at the angle it needs,
in an order that lets the assembly be built up rather than requiring a part to
be in two places at once.

This is exactly the class of thing this project is good at checking, because it
is geometric: sweep a driver shaft and handle down each fastener axis and
intersect it against the assembled solids.

**Exit criterion.** For every fastener, a driver of realistic dimensions
(shaft diameter, shaft length, handle envelope) reaches its head without
intersecting any part, in a stated assembly order. Control-tested by moving a
bolt somewhere unreachable and confirming the check screams.

**Prediction, recorded so it can be wrong:** this finds at least one
unreachable fastener. If it finds none on the first run, be suspicious of the
check before believing the result.

**Outcome, 2026-08-02.** It found four, on each roll bracket, and held them for
a week. All four were false: they are the roll servo's horn screws, which are
fitted on the bench before the bracket goes near the robot, and the check had
been measuring each screw's distance to its servo from the CASE centre rather
than from the shaft, 12.5 mm away. The prediction told us to be suspicious of a
check that found nothing. The lesson is the other one: **be equally suspicious
of a check that finds something and then never resolves it.** A red that sits
still for a week is not evidence, it is furniture. See
[status/2026-08-02](../status/2026-08-02-status.md).

---

### 4. Wire routing: completely unmodelled

**Status: the item most likely to force a reprint.**

Ten daisy-chained bus servos. Cables cross every joint, including **one that
rotates 90 degrees**. There is not one cable, channel, tie point or strain
relief anywhere in the CAD.

Why this is dangerous rather than merely incomplete:

- cable bundles need volume, and this robot's spare volume is already spoken
  for. The envelope work found exactly one legal location for the ankle-pitch
  bearing; a cable run has to fit in what is left.
- the ankle roll joint turns 90 degrees. A cable crossing it needs a service
  loop with a bend radius, and it must not snag, chafe or bind at either end of
  travel or anywhere between. That is the same swept-envelope question the flip
  already needed, applied to a flexible object.
- strain relief has to bolt to something, and mounting features are exactly the
  kind of thing that gets discovered after printing.

**Exit criterion.** Every cable run modelled as a swept volume with a stated
minimum bend radius, checked against the assembled robot in both modes and
through the flip, with tie or channel features present in the parts that carry
them.

---

### 5. Tolerance stacks beyond the wheel

**Status: partially done. The wheel is covered; nothing else is.**

`cad/assemble_check.py` now reports minimum distance and fails a running
clearance under 0.8 mm, but `running_pair()` only treats the **wheel** as a
running pair, because it is the only continuously rotating body. That was the
right call for the check that caught the 0.1 mm rub, and it leaves two gaps:

- **static chains are unchecked.** Four parts in a row, each ±0.3 mm, is a
  ±0.6 mm worst-case relative error that no single pairwise gap sees.
- **limited-travel joints are only checked at poses.** `fitcheck.py` sweeps the
  flip in 26 poses, which is a sampling, not a proof, and it uses nominal
  geometry with no tolerance applied at all.

**Exit criterion.** A worst-case stack computed along each assembly chain, and
the flip sweep re-run with parts perturbed by the service tolerance rather than
at nominal.

**DONE, 2026-08-02.** `cad.assemble_check.sweep_stack()` applies the chain-depth
stack at every step of the flip, not just at the two rest poses. Nothing closes
anywhere: the tightest is the roll bracket against the wheel, 0.90 mm nominal
across 2 interfaces, so **0.30 mm at worst case**, and it holds that value right
through the manoeuvre because the two turn together. Control-tested by loosening
the service to +/-0.5 mm, which closes 14 pairs.

Analytic rather than perturbed, for the reason `stack()` already records:
offsetting these solids by 0.3 mm fails outright in OCC, and assuming every
error lines up the wrong way is what worst case means anyway.

**And the sweep had never been running.** `stack`, `sweep` and `sweep_stack` all
existed while `uv run python -m cad.assemble_check` called none of them - the
entry point did the two rest poses and stopped. So the flip sweep on real
solids, written 2026-08-01 and the first thing ever to sweep this robot on its
actual geometry, only ran when somebody imported it by hand. All four now run
from the one command, which takes a few minutes rather than one.

---

### 6. The FEA's own confidence

**Status: two known holes, both cheap to close.**

**Mesh convergence has never been run.** The solver is verified against a
cantilever (+1.9% deflection, +3.1% stress), which validates the *element*, not
the *mesh density on these parts*. Peaks could move with refinement, and the
margins that matter are thin: the shin sits at 86% and the roll bracket at 94%
in PA6-CF. A 20% peak shift changes the answer for both.

**There is no fatigue analysis.** Everything is static ultimate. Stage 2's exit
criterion is 20 consecutive transitions, and the design intent is thousands.
A part at 94% of ultimate can fail after ten thousand cycles at a fraction of
that load, and printed parts are worse at this than the handbook figures for
the bulk polymer.

**Exit criterion.** Each part solved at two or three mesh densities with the
peak reported, so the trend is visible rather than assumed; and a cycle count
with a knockdown applied to the two parts above 80%.

> **RETRACTED, later the same day. This item does NOT close, and the risk it
> describes is worse than when it was written.** Everything below was computed
> on meshes containing inverted elements - tets with a flipped Jacobian, which
> make the stiffness matrix indefinite and quietly UNDERSTATE stress. Six of
> the seven parts were affected. On valid meshes the roll bracket is at **99%**
> of PA6-CF, not 70%, and the shin is at **83%**, not 61%. See `docs/stress.md`.
>
> So the two thin margins this item was written about are not gone. One of them
> is thinner than the 94% that prompted writing it, and the reason nobody
> noticed is that the solver returned plausible numbers from a broken mesh for
> weeks. `cad/fea.py` now refuses to return an invalid mesh at all.
>
> **Re-run, and the numbers hold.** Convergence on valid meshes:
>
> ```
> roll bracket   57.00 / 56.41 / 56.40 MPa   at 3.0 / 2.6 / 2.2 mm
> shin           47.59 / 47.83 / 48.07 MPa
> ```
>
> Both flat to 1%, so 56.4 MPa is the roll bracket's answer and not a meshing
> artifact. **99% of PA6-CF, converged.** Fatigue at 10 000 cycles is fine on
> both - the roll bracket is at 74% of its endurance limit in plane, 56% across
> layers - so fatigue is NOT the constraint. The static margin is, and there
> is none.
>
> **This is now a geometry problem, not an analysis problem**, and it is the
> thing that blocks an order. See item 8 below.

**Superseded, kept for the record.** Both parts, both studies, on meshes that
turned out to be invalid.

| | mesh 3.0 / 2.6 / 2.2 mm | static, PA6-CF | fatigue @ 10k |
|---|---|---|---|
| roll bracket | 40.69 / 39.78 / 39.94 MPa | **70%** | 52% in-plane, 32% interlayer |
| shin | 34.46 / 34.80 / 34.64 MPa | **61%** | 23% / 23% |

Both peaks are flat to within 2% across three densities, so they are answers
rather than artifacts of how finely the part was chopped. Neither is close to
its endurance limit, and **0 of 8 material pairs fail in fatigue for the shin**.

**Neither of the two "thin margins" this item was written about still exists.**
It said the shin sits at 86% and the roll bracket at 94%, and warned that a 20%
peak shift under refinement would change the answer for both. Refined: the peaks
barely move. The numbers themselves were simply old - the shin is 61% and has
been through redesigns since 86% was recorded, and the roll bracket came off 94%
when its servo cradle added material in the load path.

So the risk this item exists to flag is not merely quantified, it is gone, and
it had been gone for a while without anyone re-running the numbers to notice.
The remaining fiction is the material properties themselves, which are
literature values: that is the validation order's job, not the solver's.

---

### 7. Refresh the entry documents

`before-you-order.md` is the first thing anyone reads and it is now stale:
1.863 kg (it is 1.907 as of 2026-08-02, and was 1.858 when this was written -
the number has moved twice since, which is the argument for this item rather
than against it), the wheel before it had tread or retention, no mention of the
material sourcing conclusion, and the risk framing corrected at the top of this
file. Its mass line is now correct; the rest of the item stands.

`docs/bom.md` is covered by item 1.

---

## Suggested sequence

Items 1 to 3 are one conversation, because writing the order sheet forces the
fastener decision, and the fastener decision is what tool access is checked
against. Do them together.

```
  1 + 2 + 3   order sheet, fastener spec, tool access      <- start here
  4           wire routing
  5           tolerance stacks
  --- place the $30 validation order ---
  6           mesh convergence and fatigue, while it ships
  --- measure the coupons, correct the CAD ---
  7           refresh the entry docs
  --- place the real order ---
```

Item 6 goes while the validation order is in transit because it needs no
hardware and it is the only item on this list that can be done in parallel.

---
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

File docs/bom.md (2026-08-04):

# Bill of materials, and what modelling it at real size revealed

The sim now draws the actual parts at their actual dimensions. The visual
geometry carries no mass and no collision - mass still lives on the simple
shapes, moved to geom group 4 and hidden - so nothing here changes the
dynamics. What it does change is that packaging problems become visible.

## Parts

**The order sheet moved to `order-sheet.md`.** What was here was written before
the CAD port and could not be ordered from: it listed the servo at its invented
dimensions (45.2 x 24.7 x 35.4, really 45.4 x 24.8 x 39.6), the wheel as a
bought $8 part when it is printed in two pieces, and 400 g of PETG structure
against a real 165 g of PA6-CF. It had no fasteners, bearings, belt, pulleys or
cables, which is most of the part count. Total mass 2.05 kg against a real
1.907 - then 1.800 when the ankle-pitch servos and their belt drive came out on
2026-08-03, and 1.770 when the shin gave up their mount a day later.
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

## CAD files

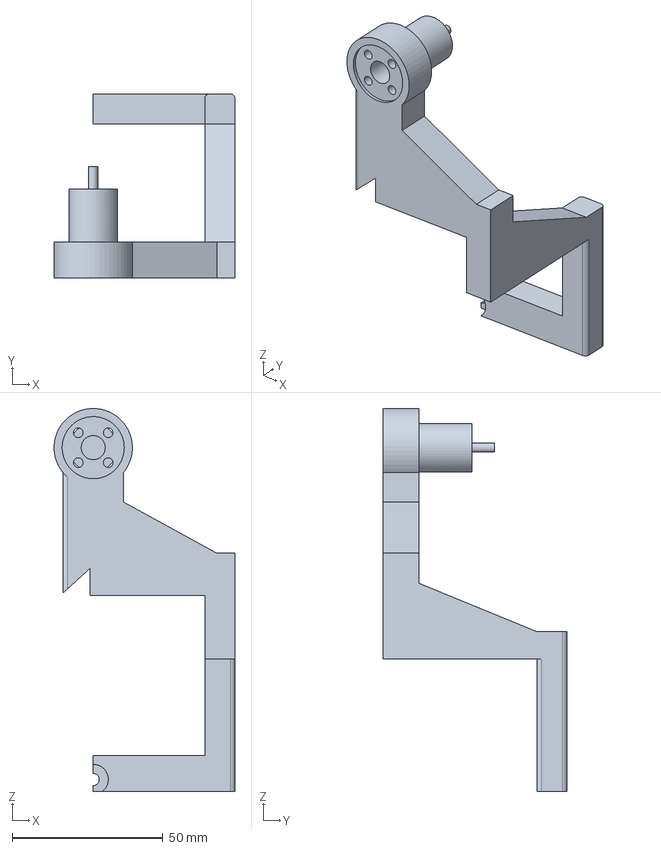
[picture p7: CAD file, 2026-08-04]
build/shin.step
60.0 x 61.0 x 127.0 mm

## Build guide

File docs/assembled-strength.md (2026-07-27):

# Strength with the robot assembled

`cad/stress.py` solves every part **alone**, rigidly clamped at its own bolt
holes. That is the right way to size a part, and it is wrong in two ways for
answering "will the robot work":

- a rigid clamp is a wall where a compliant neighbour should be, and
- nothing ever adds the deflections up.

So the leg is now also solved as **one fused solid**, held at the hip and
loaded at the wheel. `cad/assemble_check.py: fused_leg()` builds it from the
posed parts, `cad/stress.py` has it as `leg_assembly`.

## What it says

PA6-CF, at the factored (flip x3) load:

| | deflection |
|---|---|
| thigh | 2.01 mm |
| shin | 8.70 mm |
| ankle yoke | 1.28 mm |
| roll bracket | 2.46 mm |
| **sum of the isolated parts** | **14.45 mm** |
| **fused leg, one solve** | **13.23 mm** |

**The two agree to 8%.** That is the useful result, and it cuts the way you
want: it means the per-part method has not been quietly lying. The assembly
comes out slightly stiffer because fusing across a servo output shaft models
that joint as rigid (see the caveat below), and slightly softer load sharing
elsewhere does not make up the difference.

Full material table, `uv run python -m cad.stress leg_assembly`:

| material | peak MPa | in-plane | interlayer | deflection |
|---|---|---|---|---|
| PETG | 20.9 | 74% | 55% | 39.7 mm |
| PLA | 20.9 | 63% | 43% | 22.7 mm |
| ABS | 20.9 | 92% | 71% | 36.1 mm |
| **PA6-CF** | 20.9 | **37%** | **32%** | **13.2 mm** |
| MJF PA12 | 20.9 | 44% | 15% | 44.1 mm |
| SLS PA12GF | 20.9 | 47% | 16% | 30.5 mm |
| FDM PA12CF | 20.9 | 50% | 40% | 19.9 mm |
| Al 6061-T6 | 20.9 | 8% | 3% | 1.2 mm |

13.2 mm is at the **ultimate** load. At 1x service it is 4.4 mm.

## Three things this model is NOT

**It does not supersede the per-part stress numbers.** Its mesh is
curvature-driven and coarse in the bulk, so it under-resolves the very stress
concentrations the per-part solves exist to find - which is exactly why its
peak reads 21.2 MPa where the shin alone reads 49.6. Per-part remains
authoritative for stress; this model is for the global load path and for
deflection.

**It is a lower bound on deflection.** Fusing across the servo output shafts
models every joint as rigid. Real gearboxes wind up under load, and the servos
have 0.87 deg of measured backlash on top of that - 0.87 deg at the ankle is
1.7 mm at the wheel before the structure has bent at all. The real leg is
softer than 13.2 mm.

**It does not answer the running-clearance question.** The wheel and the roll
bracket are 0.9 mm apart and both hang off the end of the leg, so most of the
13.2 mm is global tip motion they make *together* and it does not close the
gap. What could close it is differential bending across the arm, and this model
still cannot see that, because the wheel itself is not in it - it turns, so it
cannot be fused to anything.

## What fusing it found: the wheel servo was on a standoff

Fusing is a check in its own right, because an exact boolean union only closes
if the parts really touch. The first attempt returned **two solids**. The
second was the wheel-drive servo: it sat **0.5 mm off** the roll bracket arm it
bolts to.

It came from `ROLL_ARM` starting at z = 12.9 when the servo's face is at 12.4 -
somebody cleared a 0.05 mm interference by moving 0.55 mm. It measured 0.500 mm
both at HEAD and after the arm was moved for wheel clearance, so it was old and
it was not a side effect of that work. Nothing had ever reported it, because
`assemble_check` only tested for interference and 0.5 mm of air reads exactly
like 20 mm of air.

Why it matters: the servo's reaction is a force couple across its mounting
bolts, and this project has already been bitten by exactly that. From the
2026-07-26 status report, on the *ankle* servo:

> Its bolts were 12 mm apart. Its 1.63 N.m reaction is a force couple, so that
> is 136 N per bolt. This is the class of fault that survives assembly and
> fails a week later.

On a 0.5 mm standoff those bolts also work in bending rather than shear, and
the joint has no friction preload at all.

**Fixed.** `ROLL_ARM` now starts at z = 12.40, exactly the servo face, so the
arm seats flat the way the other bolted faces in this robot do. The gap is
0.0000 mm with 0.00 mm3 of interference - the case is a bought part and the
bracket may not eat into it. `assemble_check` now counts 16 seated faces
instead of 14, the leg fuses into one solid, and the roll bracket came out
slightly stronger for the thicker arm (96 -> 94% in PA6-CF).

`test_every_servo_seats_flat_on_what_it_bolts_to` checks all four mounts, so
the next one cannot drift the same way.

### One modelling note that came out of it

With the servo fused in, the solve stopped converging - residual 17x the
applied load - and the cause was specific: the load was being applied to the
servo's own nodes. It is a bought box joined to the leg over a single
22.7 x 10.8 mm face, and pushing on the far side of it conditions the system
badly. The load now goes on the arm patch the servo bolts through, which is
where the wheel's reaction enters the *printed* structure and is the same
idealisation the per-part roll_bracket entry makes. The servo stays in the
solid, so it still has to seat and still carries its mass. Deflection agrees
between the two placements to 0.02 mm.

## Running it

```bash
uv run python -m cad.stress leg_assembly    # ~40 s, 38k nodes
uv run python -m cad.stress                 # everything, per part
```

The assembly is meshed with curvature-driven sizing rather than uniform.
Uniform sizing has to resolve the M2 holes everywhere, which the 230 mm leg
turns into 105k nodes and 314k DOF - and the direct solve does not converge
there, returning a residual 128x the applied load. `cad/fea.py: mesh_step` now
takes a `curvature` argument for this.

## CPU

`cad/__init__.py` caps BLAS, OpenMP and gmsh to half the machine's cores,
because these runs otherwise take every core and the desktop stops responding.
Override with `RSBOT_THREADS=n`, or `RSBOT_THREADS=0` for no cap.

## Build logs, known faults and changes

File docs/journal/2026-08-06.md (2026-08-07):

# Journal - 2026-08-06

A long session, and the shape of it is worth writing down because it is the
shape the whole project keeps taking: the parts were fine, the checks were the
problem, and every "bug" was one layer out from where it first looked.

## Where it started

Picked up the branch at four servos floating half a millimetre off the parts
they bolt to - held by nothing, and green on every connectivity check because
each one still hung on the assembly through its own horn. Gave them seating
faces. The hip took a clean end wall. The roll servo could not: any seat on the
shaft axis lives inside the servo's own interference envelope, so it got a
single datum wall instead. Straightforward, or it looked it - the hip seat I
added came back as a non-manifold chassis STL, four open edges, the kind a print
service rejects before it quotes. Caught only by printability, because a
zero-width crack weighs nothing and interferes with nothing. Ran the wall out to
share a face instead of meeting along an edge. Fixed.

## The robot was weighed in the wrong plastic

Then the mass. The printed structure had been quoted at PETG's 1.270 g/cm3
because that is what it was costed in - but it is ordered in PA6-CF at 1.19. The
density was copied across five files. Pulled it into one, cad/material.py, and
the robot came out 22 g lighter: 1748.9 g, and the balancer still stands and
rejects a shove at the new mass. One number, five places, the repo's oldest
rule broken five ways.

## Two open items that were never real

The "shin reaches y=136" item turned out to be a ghost - the belt that pushed
the bearing out there was deleted days ago, the bearing came home to y=71, and
only the comment stayed behind. Struck it. The "FEA is optimistic about infill"
item was backwards: the allowable is already knocked 0.60. What was wrong was a
comment claiming stiffness was knocked too; it was not. Fixed the comment, not
the code, and did NOT nearly-double every deflection into a number the parts do
not have.

## The rod, finally solved

cad.stress had never touched a linkage rod. Turned out it should not - the rod
is buckling-limited, and a linear-static solver cannot see buckling. But the
tension case, the pin eye, nobody had solved. Pointed cad.fea at it: 2% of
allowable, buckling 20x. And the buckling test had frozen a stale torque while
its own docstring said "measured, not a literal." Made it live.

## The fasteners, and the day's real lesson

Checked whether the CAD holes matched the bolt list. They did not. Sixteen
heat-set inserts on the order sheet with no 3.5 mm bore anywhere in the
geometry - a dead constant and a clearance hole where an insert wanted a bore.
Wrote the check that catches it, then cut the bores: the Pi standoffs, and -
after dropping eight inserts for a chassis joint that does not exist on a
one-piece print - two set screws per yoke to retain the ankle-pitch shaft.

That last one is where the day earned its length. Placing the yoke inserts
turned the suite red on two FEA tests. The bore was the obvious suspect. I built
a whole mechanism to route the global mesh around it - and the routed-around
version failed identically. The bore was innocent. The whole-leg FEA had been
reading a STALE step file off disk, passing on old geometry while the parts
moved underneath it; regenerating it exposed that the mesher emits a single
orphan node, and one node with no stiffness makes the entire matrix singular.
Pinned orphan nodes in the solver, reverted the wrong fix, and the leg converged
again. Full suite: 109 passed.

## What I keep relearning here

The thing you changed last is the loudest suspect and usually the wrong one. The
control - does it still break without my change - is what points at the truth.
And a green check is not evidence; it is a claim, and half of them today were
reading a copy, a stale file, or the wrong plastic.

## Where it leaves us

Everything the digital twin can settle on its own is settled and green. The two
open items - real PA6-CF strength, gear backlash - both need a physical part, and
that is the $30 validation order, not more simulation. The model has, as far as
its own checks can prove, converged.

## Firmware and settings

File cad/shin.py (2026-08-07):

"""The shin, as a real printable part.  uv run python cad/shin.py

Built from the dimensions the simulator already uses, so the CAD and the sim
describe the same object. Adds what a real part needs and a parametric sketch
does not: a hub to bolt onto the knee servo horn, a bearing bore for the ankle
pitch axis, and M2 clearance holes for the ankle servo.

Outputs STEP (to print or machine) and STL (as a MuJoCo asset), and reports
mass from the solid rather than from an estimate.

Frame matches the sim's shin body: origin at the knee, z negative downward,
ankle axis at z = -110. Millimetres.
"""

import sys
from pathlib import Path

import build123d as bd
import numpy as np

# --- cable channel -------------------------------------------------------------
#
# The bus lead from this part's servo to the next runs straight through here.
# cad/wiring.py found it, and the runs are modelled as the STRAIGHT LINE between
# measured connector ports - the shortest possible path - so anything it hits is
# hit by every real routing too.
#
# Cut at CABLE_CH_R, the 4.4 mm bundle plus room to lay it in without pinching.
# A relief where the path grazes the surface, a tunnel where it does not; either
# way it is the cable's space reserved, instead of discovered at the bench with
# the parts already printed.
# The endpoints are NOT stored here any more. They were, and they went stale
# three times in one day: moving the hip and wheel servos onto their own joints
# moved their connector ports, and correcting the case height from the STEP's
# 39.6 to the drawing's 36.5 then moved all ten of them by 1.15 mm. Eight of
# eight runs ended up passing through solid material and nothing but
# cad/wiring.py could see it.
#
# cad.wiring.channel() cuts the run where the run actually is, in both poses,
# every build. A number that has to be retyped whenever the robot moves is a
# number that will be wrong the next time the robot moves.
CABLE_CH_R = 3.0
# Two paths, not one: the run pivots slightly at the knee end between wheel
# mode and foot mode, and the channel has to hold the cable in BOTH poses.
# Cutting only the wheel-mode line left 4 mm3 of foot-mode interference -
# small, but foot mode is the pose the robot stands in.

# The OUTGOING lead, ankle servo to roll servo. It leaves the port at CABLE_B
# and drops away aft and down, and until the cradle went in it left through open
# air. The +x wall now stands in it, by 7 mm3. Same catch as on the yoke: fitcheck
# and assemble_check were both clean, because neither of them models a cable.
# The far end is on the yoke, which moves between the poses, so two paths again.



OUT = Path(__file__).parent / "out"

# PA6-CF, one source. A print is not solid plastic: 4 perimeters and ~40% gyroid
# on a part this size lands near 60% of solid. Measure a real print and correct
# INFILL in cad/material.py.
from cad.material import DENSITY as PRINT_DENSITY, INFILL

# --- geometry, straight from the sim -----------------------------------------
SPINE_Y, SPY = 21.0, 6.0      # spine centre-line and half-thickness
ANKLE_Z = -110.0

# The ankle-pitch bearing sits at (0, PITCH_Y, ANKLE_Z) - ON the axis, which
# the old bore was 52.8 mm away from. `cad/envelope.py` solves for where it is
# allowed to be, and there are exactly two bands: y = -80..-47 inboard and
# y = +56..+80 outboard. Everything between is inside the wheel in one of its
# two shapes, or inside the wheel-drive servo.
#
# Outboard wins. The leg already reaches y = 69 at the ankle-pitch servo, so
# this costs no width at all, and inboard would put the two legs' bearings
# 6 mm apart across the centreline.
# y = 68, not 67, and the band starts at 57 not 56: the wheel-drive servo
# TURNS with the roll bracket, and its far corner swings out to 50.9 mm,
# 1.5 mm past its static face. Treating it as a fixed box put this boss where
# fitcheck found it being clipped 0.9 mm at 16% of the flip.
PITCH_Y = 71.0                # bearing centre
PITCH_HALF = 5.0              # bearing block half-width in y

SPINE = ((-10, 10), (SPINE_Y - SPY, SPINE_Y + SPY), (-49, 0))

# The route to the bearing goes FORWARD, and both halves of that are forced.
#
# It cannot go down the middle: the wheel-drive servo turns with the roll
# bracket, so it sweeps an annulus 14..50.9 mm about the roll axis for
# |x| < 22.6, and that swallows everything below z = -55 near the centreline.
# So the shin has to leave at |x| > 22.6 - and further than that, because the
# servo PITCHES too: its corner swings out to sqrt(22.6^2 + 12.35^2) = 25.8 mm.
# Sweeping only roll put these members at x = 23 and fitcheck found them
# clipped 2.4 mm at 64% of the flip.
#
# It cannot go AFT either, which is what the first two attempts did. In foot
# mode the axle is 12 mm off the floor and the shin stands at 27.5 deg, so
# structure hanging aft at axle height swings down: the aft version ended up
# 13 mm THROUGH the floor. Forward, the same tilt lifts it.
FARM = ((10, 47), (SPINE_Y - SPY, SPINE_Y + SPY), (-49, -35))
FPOST = ((37, 47), (SPINE_Y - SPY, SPINE_Y + SPY), (-70, -48))
# 9 mm deep, and it cannot be more. Deepening it to 15 buys 116% -> 107% of
# PETG's allowable and then collides with the wheel-drive servo 5.3 mm deep at
# 64% of the flip: the servo sweeps that space and there is nowhere to put the
# extra section. The rib below is what carries this member instead.
CROSS = ((37, 47), (SPINE_Y - SPY, PITCH_Y + PITCH_HALF), (-70, -61))
DROP = ((37, 47), (PITCH_Y - PITCH_HALF, PITCH_Y + PITCH_HALF), (-114, -61))
BACK = ((0, 47), (PITCH_Y - PITCH_HALF, PITCH_Y + PITCH_HALF), (-114, -102))
# --- what used to be the ankle-pitch servo mount -------------------------------
#
# GONE, 2026-08-04. The ankle-pitch servo was deleted on 2026-08-03 when the
# parallelogram went in (cad/linkage.py) and its mount outlived it by a day:
# STANDOFF, two cradle side walls, an upper end wall and a clearance pocket, all
# holding a part that is not on the order sheet. 53.05 cm3 -> 45.11, about 6 g
# a leg, off the part with the least mass left to give.
#
# WHAT IS STILL HERE AND WHY. The forward carrier - FARM, FPOST, CROSS, DROP,
# BACK - reaches y = 76 to hold the ankle-pitch bearing at PITCH_Y = 71, which
# is where the envelope forces it (see the band note above: outboard 56..80 is
# the only room, inboard collides with the wheel or pairs the two bearings 6 mm
# apart). This is not a leftover awaiting a decision. The belt-era claim that it
# "reaches y = 136 and moving it in is a kinematics decision" was stale from the
# day the belt left on 2026-08-03: the bore came back on-axis and the carrier
# came in with it. The number outlived the part in this comment and in two
# status reports before anyone measured the built shin (15..76 mm).
#
# The diagonal relief further down stays too, and it is easy to misread now that
# its comment mentions the standoff: it clears the WHEEL-DRIVE servo sweeping
# past during the roll, not the ankle servo. Rebuilt without it the part is
# 45.64 cm3, so it is still cutting 0.53 cm3 of real material.
#
# THE OLD COMMENT HERE WAS WRONG, AND IT MATTERED. It read "runs the length of
# the ankle servo's case so its mounting bolts can be far apart: 1.63 N.m
# through bolts 12 mm apart is 136 N each, at 40 mm it is 41." The bolts were at
# z = -60 and -20, the servo case ran -56.5..-11.1, so the z = -60 bolt was
# 3.5 mm off the END of the servo and missed the standoff too. The shin has had
# ONE ankle-servo bolt, not two, and that 41 N argument was computed for a pair
# that never existed. Kept because it is the clearest example in this file of a
# number that reads like engineering and was never checked against the geometry.

# --- fasteners ---------------------------------------------------------------
HUB_R = 13.0                  # hub outer radius
HORN_BORE = 4.0               # radius, clearance over the servo output boss
# The real horn pattern, from cad/servo.py: a 9.9 x 10.0 mm rectangle. It was
# a bolt circle at r = 8, so every hole was 0.71 mm out of position.
from cad.servo import HORN_DX, HORN_DY, HORN_SCREW_R
BEARING_OD = 5.0              # radius, 623ZZ outer race (10 mm dia)
BEARING_W = 4.0               # 623ZZ width
SHAFT_R = 2.0                 # radius, clearance for the 3 mm shaft


# Ribs at the two inside corners, in the x-z plane and across the full 12 mm
# width, so they lie IN the layer plane where the material is strong. The shin
# passed at 89% of PETG's allowable, which is passing with nothing to spare;
# a triangle at a corner is the cheapest way to buy that back, because bending
# stiffness goes as depth cubed and a rib is all depth.
RIB_SPINE = ((10, -35), (10, -18), (41, -35))      # spine to forward arm
# The two hottest places on the part, both re-entrant corners, found by asking
# the FEA rather than by eye: 80 MPa where the outboard crossing meets the
# descent, and 68 MPa where the forward column meets the crossing. Triangles
# in the y-z plane, across the full 10 mm width of those members.
# One rib, running the full width to the descent, so it ends ON something.
RIB_CROSS = ((27, -61), (27, -45), (66, -61))     # column to crossing
RIB_X = (37.0, 47.0)
# (the arm-to-post rib went with the post's lower half)


def _gusset_yz(pts_yz, x0, t):
    """Triangular rib in the y-z plane, spanning x0 to x0 + t. Same
    measure-don't-trust-the-normal treatment as _gusset."""
    g = bd.extrude(bd.Plane.YZ * bd.Polygon(*pts_yz), amount=t)
    return bd.Pos(x0 - g.bounding_box().min.X, 0, 0) * g


def _gusset(pts_xz, y0, t):
    """Triangular rib in the x-z plane, spanning y0 to y0 + t.

    Normalised by MEASUREMENT rather than by trusting the extrude direction.
    `bd.extrude` follows the face normal, and that normal flips with the
    polygon's winding order, so the identical call places the rib at
    y0..y0+t for one point order and y0+t..y0+2t for the other. The shin's rib
    landed 12 mm out of position that way, sitting inside the ankle servo, and
    nothing but cad/envelope.py would have noticed.
    """
    g = bd.extrude(bd.Plane.XZ * bd.Polygon(*pts_xz), amount=t)
    return bd.Pos(0, y0 - g.bounding_box().min.Y, 0) * g


def _box(spec):
    (x0, x1), (y0, y1), (z0, z1) = spec
    return bd.Pos((x0 + x1) / 2, (y0 + y1) / 2, (z0 + z1) / 2) * bd.Box(
        x1 - x0, y1 - y0, z1 - z0)


def build():
    part = (_box(SPINE) + _box(FARM) + _box(FPOST)
            + _box(CROSS) + _box(DROP) + _box(BACK))
    part += _gusset(RIB_SPINE, SPINE_Y - SPY, 2 * SPY)
    part += _gusset_yz(RIB_CROSS, RIB_X[0], RIB_X[1] - RIB_X[0])

    # Hub at the knee, bolted to the servo horn. It must be centred ON the
    # knee axis at z = 0, or the part does not pivot about the joint - it was
    # 14 mm below it, which no amount of stress margin would have saved.
    part += bd.Pos(0, SPINE_Y, 0) * bd.Rot(90, 0, 0) * bd.Cylinder(HUB_R, 12)
    part -= bd.Pos(0, SPINE_Y, 0) * bd.Rot(90, 0, 0) * bd.Cylinder(HORN_BORE, 14)
    # Horn pocket, on the face that meets the knee servo. Without it this hub
    # lands 1.10 mm INSIDE the horn: the part was positioned at the spline tip
    # and the horn finishes 1.10 mm beyond it. See cad/servo.py HORN_PROUD.
    from cad.servo import HORN_POCKET_R as _HPR, HORN_POCKET_T as _HPT
    part -= (bd.Pos(0, SPINE_Y - SPY + _HPT / 2, 0) * bd.Rot(90, 0, 0)
             * bd.Cylinder(_HPR, _HPT))
    for dx in (-HORN_DX, HORN_DX):
        for dz in (-HORN_DY, HORN_DY):
            part -= (bd.Pos(dx, SPINE_Y, dz) * bd.Rot(90, 0, 0)
                     * bd.Cylinder(HORN_SCREW_R, 20))

    # Ankle pitch bearing: a 623ZZ pressed into a counterbore, with a
    # clearance hole through for the shaft. A plain hole would run the shaft
    # straight against printed plastic.
    #
    # ON the axis this time. The old one was at (-48, 21, -88), which is
    # 52.8 mm from the line the sim rotates this joint about, so the part
    # could not have pivoted about its own joint - the same fault as the knee
    # hub, and a bigger instance of it.
    part -= (bd.Pos(0, PITCH_Y, ANKLE_Z) * bd.Rot(90, 0, 0)
             * bd.Cylinder(SHAFT_R, 4 * PITCH_HALF))
    part -= (bd.Pos(0, PITCH_Y - PITCH_HALF + BEARING_W / 2, ANKLE_Z)
             * bd.Rot(90, 0, 0) * bd.Cylinder(BEARING_OD, BEARING_W))

    # Ankle-servo capture. Two walls gripping the case sides, standing off the
    # standoff face, positioned from the SERVO rather than from a guess: its
    # shaft is on the belt centre distance and the case hangs off that.
    # Positioned from the SIM's box, not from the belt centre distance. Working
    # it out as SERVO_SHAFT_Z - SHAFT_INSET gives -56.52..-11.12; the sim's
    # vanksv_l geom is at z = -33.2 +/- 22.7, so -55.9..-10.5. The 0.62 mm
    # between those two is not academic: it put the upper end wall 0.22 mm
    # inside the servo, which assemble_check caught as 57.5 mm3. The sim is what
    # the interference checks measure against, so the sim is what the part is
    # built from.
    # No lightening pocket. The first attempt cut a 10 mm slot clean through
    # a 20 mm spine, leaving a thin-necked keyhole, and the 0.73 mm stiffness
    # figure in docs/bom.md assumes a SOLID section. It saved about 2 g on a
    # 17 g part - not a trade worth making.

    # Reserve the cable run, in both poses. See CABLE_CH_R.
    from cad.wiring import channel as _channel
    part = _channel(part, "vkneesv_l -> vanksv_l", "shin_l", r=CABLE_CH_R)
    part = _channel(part, "vanksv_l -> vrollsv_l", "shin_l", r=CABLE_CH_R)

    part = part.clean()
    from cad.shape import long_edges, soften
    part, build.corner_r = soften(part, long_edges(part, "z", 40.0),
                                  radii=(1.5, 1.0, 0.8), what="shin verticals")

    # RELIEF, CUT AFTER THE FILLET, and it has to be after or it does nothing.
    #
    # Widening the standoff gave soften() new long z-edges to work on, and the
    # r = 1.0 blend where a cradle wall rises off the seating face is CONCAVE:
    # it adds material, 0.2 mm of it, straight into the space the servo has to
    # sit in. assemble_check found 3.4 mm3. Nobody would have seen it on a
    # drawing, and the result at the bench is a servo rocking on a fillet
    # instead of seating on a face - the same fault as the 0.5 mm standoff this
    # design has already been bitten by once, minus the bolts that used to
    # tighten it out.
    #
    # So the pocket is defined by the SERVO rather than by whatever the fillet
    # leaves behind: subtract the case, grown by the clearance in x and z, and
    # open-ended in +y so the seating face itself survives.
    # THE WHEEL SERVO SWEEPS THROUGH THIS CORNER, and only the solid sweep sees
    # it. cad/assemble_check.sweep() puts 17.3 mm3 of wheel servo inside the
    # shin's aft-bottom corner at half flip. fitcheck missed the shape of it
    # because it sweeps the sim's BOXES, and a box cannot carry a chamfer.
    #
    # The cut is diagonal, not a square corner, because the overlap is: the
    # servo comes in from below and aft and rises toward +x as the ankle rolls,
    # so the boundary runs from (-17, -54.5) up to (-1, -40.0). A square relief
    # deep enough to clear it would take the standoff's whole aft end, which is
    # the face the ankle servo mounts against.
    part -= bd.extrude(
        bd.Plane.XZ * bd.Polygon((-17, -58), (-17, -54.5), (-1, -40.0),
                                 (-1, -58)),
        amount=26.0).moved(bd.Location((0, 10.0, 0)))

    # THE IDLER TURNS ON THIS PART. cad/linkage.py's bar rides on a stub axle
    # coaxial with the knee, and the shin is what is out there: probing the
    # knee axis finds the knee servo to y = 15, this part to y = 32, and air
    # past that. A fat printed boss rather than a 3 mm shaft, because 0.03 mm
    # of deflection here is 0.06 deg at the foot.
    from cad.linkage_mounts import knee_stub
    part += knee_stub()

    return part


def main(export=True):
    p = build()
    solid_cm3 = p.volume / 1000.0
    solid_g = solid_cm3 * PRINT_DENSITY
    printed_g = solid_g * INFILL

    if export:
        OUT.mkdir(exist_ok=True)
        bd.export_step(p, str(OUT / "shin.step"))
        bd.export_stl(p, str(OUT / "shin.stl"),
                      tolerance=0.01, angular_tolerance=0.1)

    bb = p.bounding_box()
    print(f"bounding box   {bb.size.X:.1f} x {bb.size.Y:.1f} x {bb.size.Z:.1f} mm")
    print(f"solid volume   {solid_cm3:.2f} cm3")
    print(f"solid PA6-CF   {solid_g:.1f} g")
    print(f"printed @{INFILL:.0%}   {printed_g:.1f} g   <- use this")
    c = p.center()
    print(f"centroid       ({c.X:+.1f}, {c.Y:+.1f}, {c.Z:+.1f}) mm")
    return printed_g / 1000.0


if __name__ == "__main__":
    main(export="--no-export" not in sys.argv)

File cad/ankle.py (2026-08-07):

"""Ankle yoke and roll bracket.  uv run python cad/ankle.py

Two small parts, both in the ankle body's frame with the origin at the AXLE.

  ankle yoke     carries the roll servo and the ankle-pitch bearing
  roll bracket   carries the wheel servo, and rolls 90 deg with it

They are small but they sit in the tightest region of the robot: three joints
inside 45 mm, two of which must clear a wheel that changes shape halfway
through the manoeuvre. See docs/porting-a-link.md for the clearance rules.
"""

import sys
from pathlib import Path

import build123d as bd
import numpy as np

# --- cable channel, roll servo to wheel servo ----------------------------------
#
# This run crosses the ankle ROLL joint, so its far end is on a bracket that
# turns 90 degrees and the cable sweeps a long arc between the modes. Only the
# end anchored on this part stays put.
#
# So both extremes get a channel: the cable has to live somewhere in both poses,
# and reserving one of them reserves the wrong one half the time. cad/wiring.py
# measures the length change at 6.3 mm, which is the service loop this has to
# let it take up.
# The endpoints are NOT stored here any more. They were, and they went stale
# three times in one day: moving the hip and wheel servos onto their own joints
# moved their connector ports, and correcting the case height from the STEP's
# 39.6 to the drawing's 36.5 then moved all ten of them by 1.15 mm. Eight of
# eight runs ended up passing through solid material and nothing but
# cad/wiring.py could see it.
#
# cad.wiring.channel() cuts the run where the run actually is, in both poses,
# every build. A number that has to be retyped whenever the robot moves is a
# number that will be wrong the next time the robot moves.
CABLE_CH_R = 3.0
# x moved -0.5 -> -13.05 when the wheel servo was put on its own axis. Its
# case had been centred on the wheel axis, which left the output shaft 12.5 mm
# off the joint it drives (cad/drives.py), and the connector port moved with the
# case. The old channel then ran 38 mm3 of yoke straight through the cable.

# The ankle-servo lead, coming down the shin into the roll servo. It never
# needed a channel before, because before there was nothing here: it crossed
# open air where the cradle's +y wall now stands, and cutting that wall put
# 62 mm3 of yoke through the middle of it.
#
# Worth noting how it was caught. Not by fitcheck, not by assemble_check, both
# of which were clean - a cable is not a solid and neither of them models one.
# It was the wiring test, which asserts that the ONLY blocked run left in this
# robot is the roll-to-wheel one, by exactly the wheel envelope and nothing
# else. A test written to pin a known limit is what noticed a new one.
#
# Two paths again, for the same reason as everything else in this file: the
# yoke drops 28 mm in z between the modes, so the run's far end moves and a
# channel cut for one pose is the wrong channel half the time.



OUT = Path(__file__).parent / "out"
from cad.material import DENSITY as PRINT_DENSITY, INFILL  # PA6-CF, one source

# From the sim, millimetres, relative to the axle.
# The roll drive, drawn for the first time. Layout along the roll axis:
#
#   x = -97.6..-58   roll servo, bolted to the yoke through its CASE screws at
#                    y = +/-10.2 - outside the coupler's radius, which the old
#                    4 bolts at +/-4 were not
#   x = -56.5..-52   coupler disc, bolted to the servo's 25T horn. Belongs to
#                    the ROLL BRACKET: this is what the servo actually turns
#   x = -51..-45     yoke's bearing carrier, taking the radial load off the
#                    servo's own output bearing
#   x = -45..-41     roll bracket's hub
#
# A 3 mm shaft runs -56.5..-41 through all of it. The servo drives one end, the
# yoke bearing supports the middle, the bracket grips both ends.
from cad.servo import HORN_PROUD as _HORN_PROUD  # noqa: E402
ROLL_SV_X1 = -58.0          # the roll servo's output end; ROLL_SV asserts this

# SHORTENED from (-51, -45) to free 1.5 mm for the roll bracket's web.
#
# The post's job is to house the 623ZZ, which is 4.0 mm wide and sits at
# x = -49, so it needs -51..-47 and had -51..-45. The spare 1.5 mm was doing
# nothing, and the web next door was the most loaded part in the robot at 99%
# of PA6-CF. Measured: 4.0 mm web is 56.6 MPa, 5.5 mm is 31.4. The window
# between this post and the wheel at x = -40 is the whole budget.
POST = ((-51, -46.5), (-6, 6), (-6, 6))       # bearing carrier, on the roll axis
# The inner face is DERIVED from the horn, not typed. It read -56.5, which left
# the coupler standing 0.40 mm off the horn it bolts to - measured 2026-08-02 by
# cad.hardware.horn_joints(). The horn is 4.50 thick over a spline that stands
# 3.40 proud, so its outer face is HORN_PROUD past the servo's box end, and the
# box end here is ROLL_SV's near face.
COUPLER_X = (ROLL_SV_X1 + _HORN_PROUD, -52.0)
COUPLER_R = 9.0
ROLL_SHAFT_X = (-56.5, -41.0)   # between servo (ends -58) and the flat wheel,
                                # which needs |x| > 40

# Capturing the roll servo instead of bolting into its case. See build().
from cad.servo_dims import CRADLE_CLEAR  # noqa: E402  one copy, see there
CRADLE_WALL = 2.5
CRADLE_DEPTH = 10.0           # how far the rim reaches along the shaft
# How far up the walls run. They are carried by the ring, which stops at z = 17,
# so going much past that is a cantilever holding nothing. The grip only has to
# react a couple, and 15 mm of contact each side at a 25.5 mm arm does that.
CRADLE_Z_TOP = 19.0
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

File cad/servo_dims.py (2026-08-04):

"""The STS3215's dimensions, and nothing else.

Split out of cad/servo.py so that src/rsbot/model.py can import them without
pulling in build123d, which is a dev-group dependency and has no business being
required to load a physics model.

THE REASON THIS FILE EXISTS is that these numbers were in six places with three
different values: cad/servo.py had the STEP's 45.40 x 24.80 x 39.60, while
cad/envelope.py, cad/assemble_check.py, cad/robot.py and cad/assembly.py all
still carried 45.2 x 24.7 x 35.4 - the original product-listing guesses,
superseded twice and never updated. envelope.py is the file that solved where
the ankle bearing is allowed to live.

These are the manufacturer's drawing, for the 12 V C018 part. They are the only
copy. Import them; do not retype them.
"""

LENGTH = 45.23           # x, along the case
WIDTH = 24.73            # y, across it
HEIGHT = 36.50           # z, ALONG the output shaft, tip to tip

# and the shaft-axis breakdown, which adds up to HEIGHT exactly
SPLINE_PROUD = 3.40      # spline above the case's top face
BODY = 29.00             # the case itself
REAR_BOSS_PROUD = 4.10   # rear pivot boss below the bottom face

SHAFT_X = 12.50          # shaft axis, from the case centre, along LENGTH
SHAFT_R = 2.95           # 25T spline, 5.9 mm across
IDLER_R = 3.00           # Ø6 rear pivot boss

assert abs(SPLINE_PROUD + BODY + REAR_BOSS_PROUD - HEIGHT) < 1e-9

# --- how a printed part grips this servo ---------------------------------------
#
# 0.4 mm per side, and it must EXCEED the print tolerance: the services quote
# +/-0.3 mm, so a cradle drawn to the case size can come out 0.3 mm small and
# not go together at all.
#
# THIS NUMBER WAS IN FOUR FILES - cad/servo.py, cad/chassis.py, cad/shin.py and
# cad/ankle.py - which is the repo's own rule broken four ways at once. They all
# said 0.4, so nothing was wrong yet; that is what a second copy looks like
# right up until it is not. The WALL and DEPTH stay per-part, because those are
# real choices about how much room each mount has.
#
# It is also not free. cad/fasteners.capture() measures what it costs: 0.4 mm on
# a 24.73 mm case is up to 1.5 degrees of free rotation about the shaft, which
# adds to that joint's gear lash.
CRADLE_CLEAR = 0.4

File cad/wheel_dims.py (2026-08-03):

"""The wheel's outside dimensions, and nothing else.

Split out of cad/wheel.py for the same reason cad/servo_dims.py was split out
of cad/servo.py: so that src/rsbot/model.py can import them without pulling in
build123d, which is a dev-group dependency and has no business being required
to load a physics model.

THE REASON THIS FILE EXISTS, found 2026-08-02. These numbers were in three
places each and one of them was wrong by 5 mm:

    WHEEL_R       sim 0.040   cad/wheel.py 40.0   cad/envelope.py 40.0    agreed
    WHEEL_HALF_W  sim 0.012   cad/wheel.py 12.0   cad/envelope.py 12.0    agreed
    tyre wall     sim 0.008   cad/wheel.py  3.0                       DISAGREED

The sim's `WHEEL_TIRE_T = 0.008` said the tread is 8 mm thick. The CAD builds
3 mm, and the whole wheel design turns on that number: the rigid rim stops at
R - TYRE_T = 37, and cad/printability.py asserts there is no rigid material
outside r = 38.5 because the part has to stand on rubber, not on plastic. At
8 mm the rim would stop at 32 and the assertion would be about a different
wheel.

It survived because **nothing read it.** One definition, zero uses, wrong by
5 mm, sitting in the file that describes the robot to the physics. A constant
nobody uses is not harmless: it is a wrong answer waiting for the first person
who trusts it, and it reads as verified because it sits beside numbers that are.

The two that agreed had comments saying "the sim's WHEEL_R", which is an author
noticing the duplication, writing it down, and copying the number anyway.

These are the only copy. Import them; do not retype them.
"""

R = 40.0                 # outer radius, on the tread
HALF_W = 12.0            # half width, so the disc is 24 mm across
TYRE_T = 3.0             # tread thickness, so the rigid rim stops at r = 37

# The sole has to be rubber everywhere it can touch the floor, so no rigid
# feature may reach past this. cad/printability.py checks it.
RIGID_MAX_R = R - 1.5

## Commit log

2026-07-25 Stage 0: MuJoCo model and wheeled-balance controller
    43 cm, 1.87 kg wheeled biped with retractable rocker soles, mass-budgeted
    for the final robot so the legs are tuned against arms-and-head inertia
    rather than a bare stage-1 mass.
    The wheels are velocity-source, because that is what STS3215 servos give
    you in continuous rotation mode, so the balancer is a cascade (odometry ->
    pitch target -> wheel speed) rather than LQR on wheel torque. It reads only
    what the real robot has: IMU quat, gyro, wheel joint velocity.
    Stage-0 exit criterion met: stands 5 min unattended with 18 mm drift,
    tracks velocity commands to within 2%, and recovers attitude in 0.65-0.70 s
    from shoves up to 0.7 N.s. Falls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
    [model.py, view.py]
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2026-07-25 Stage 0b: sole sweep clearance check, and fix the ankle reference frame
    The clearance sweep turned up a real modelling bug: the ankle encoder is
    relative to the SHIN, and the shin pitches by -0.35 rad in stance and
    -0.88 rad in a deep squat. A constant ankle angle is therefore not a
    constant sole angle, so squatting would have swung the retracted sole down
    into the floor. Deploy and retract commands are now world-referenced via
    model.sole_angle(), and the ankle range widened to -0.30..3.30 rad to cover
    the squat range.
    Geometry findings, all stance-independent (the axle sits at wheel radius
    whenever the robot is on its wheels):
    deployed sole face 55 mm below axle -> wheel lifts 15 mm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
    [model.py]
2026-07-25 Stage 0b: deploy state machine, and proof the flat sole cannot work
    Builds the WHEEL->SQUAT->SETTLE->DEPLOY->LOAD->STAND machine with contact
    inferred from ankle servo tracking error rather than simulator contact
    forces, since an STS3215 has no force sensing. Contact detection works, to
    within 0.13 rad of the kinematic prediction.
    The mechanism does not. 60 physically valid sole geometries x deploy rates:
    zero reach STAND. Controller-side fixes were exhausted first (unload at
    flat vs at contact, 1.5 to 200 rad/s, deeper squat); at 60 rad/s the plate
    slams the floor and launches the robot 135 mm.
    The cause is geometric, not tuning. corner_radius = hypot(face_r, half_len),
    and face_r >= 46 m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
    [model.py]
2026-07-25 Stage 0b: replace the rocker sole with outrigger struts
    The axle-pivoted flat sole is gone. It could not work: the plate had to
    cradle the wheel, which forced a >=46 mm pivot-to-face radius, which forced
    an 11-21 mm airborne jack onto a single edge behind the axle. Documented in
    docs/stage-0b.md with the 60-configuration sweep that killed it.
    The replacement puts the strut pivot 55 mm down the shin, swinging inboard
    of the wheel where nothing has to be cradled. The sequence is built around
    the critical-state rule from the wheel-biped transformation literature -
    wheel and foot in contact simultaneously, robot never airborne:
    EXTEND to 213 mm to raise the pivot, SWING with 7.2 mm of floor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
    [model.py]
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2026-07-25 Stage 0b done: the wheel rotates flat and becomes the foot
    Third mechanism, first one that works. A 90 deg ankle roll stands the wheel's
    spin axis vertical so the disc lies down and its 80 mm face is the sole.
    Each leg is now hip pitch, knee pitch, ankle pitch, ankle roll, wheel.
    It works because it is the only design whose support polygon is CENTRED under
    the axle, which is where the CoM already is when the balancer hands over. Both
    earlier mechanisms died trying to buy fore/aft margin they could not afford:
    the axle-pivoted plate jacked the robot 11-28 mm airborne, and the outrigger
    struts held contact but capped forward margin at +8.5 mm.
    flip completes in 0.79 s, works from 0.5 to 8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
    [model.py]
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2026-07-25 Model gear backlash, and find it breaks the passive foot stance
    load(backlash=radians) puts a lash joint in series with every actuator, so
    the link can move without the motor knowing. Modelled physically rather than
    as a command deadband, because a deadband would not let the load move on its
    own, which is the part that actually hurts a balancer. backlash=0 builds the
    rigid model unchanged, so existing index-based tests still hold.
    Results, and they change the plan:
    Gains tuned rigid survive no lash at all; re-tuning is mandatory and it is
    the outer loop that moves. At 1 deg, re-tuning takes the cost from 564 to 13.
    Wheel mode then survives up to 2 deg, but at 20-25 deg of pitch swin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
    [model.py]
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2026-07-26 Model the real parts at real size, and catch three packaging faults
    Visual geometry built from actual dimensions: STS3215 bodies at
    45.2 x 24.7 x 35.4, 80 mm wheels with hubs, Pi 5, 3S pack, bus adapter,
    printed brackets. It carries no mass and no collision - mass stays on the
    simple shapes, now in hidden geom group 4 - so no dynamics result changes.
    A test enforces that, because it would be an easy thing to break silently.
    Splits the roll bracket into its own body, which is physically required: the
    wheel-drive servo bolts to it and must not spin with the wheel. Same total
    mass, same DOF count, same CoM.
    Three faults the abstract capsules were hiding, all found by checking both
    wheel and f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
    [model.py]
2026-07-26 Make the parts actually fit, add a scale reference, rebuild the viewer
    The parts were passing through each other, and an audit found 102
    interpenetrating pairs, worst at 12 mm. Two mistakes caused most of it:
    Servos were attached to the wrong body. A servo case bolts to the body
    PROXIMAL to the joint it drives, so the hip servos belong to the torso and
    the knee servo to the thigh. Hanging each off the link it drives put every
    case inside the next link.
    The output shaft was modelled along the body's long axis. On a real bus
    servo it is perpendicular, near one end of the top face, so a servo driving
    a joint occupies the plane perpendicular to that joint's axis.
    fitcheck.py doe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
    [model.py]
2026-07-26 Assemble the model properly, and add steering
    Two complaints, both real.
    FLOATING. Overlap-free is not the same as assembled, and the first pass only
    checked overlap. fitcheck.py now also builds a connectivity graph: parts are
    joined if their boxes come within 4 mm, and the robot should be one group.
    It was ELEVEN groups - a cloud of parts that happened to miss each other.
    The fix is a spine per link, running from its own joint to the child joint,
    with the child's servo bolted flush against it, and the whole structure
    routed outboard of the wheel plane. Torso internals get shelves instead of
    hovering. Now 1 group in both modes with 0 interpenetration, both enforced
    by tests.
    The rule that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
    [model.py]
2026-07-26 Check the whole flip, not just its end poses
    You were right that parts pass through each other on the way to foot mode.
    fitcheck only ever tested the two end states, and both were clean while the
    robot destroyed itself in between. It now walks the flip in 26 steps.
    The first run found the wheel-drive servo sweeping 20.7 mm THROUGH the shin
    at 64% of the flip. That servo turns with the roll bracket, so it carves an
    annulus 14-50 mm from the roll axis for |x| < 23 mm, and nothing outside the
    roll bracket may sit in it.
    That one constraint reshaped the lower leg. The annulus has a hole, though:
    parts essentially ON the roll axis are inside it and the sweep misses them
    entirely, which is where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
    [model.py]
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2026-07-26 Close the gaps inside rigid parts, and check the structure is stiff enough
    You were right that things looked like they were floating, and the metric was
    at fault. The robot-wide connectivity check used a 4 mm tolerance, which is
    correct for a running clearance ACROSS a joint - two links that rotate past
    each other must not touch - but far too generous INSIDE a rigid part.
    Checked strictly, 5 of 11 bodies were not one piece: the hip servos sat
    0.6 mm off the chassis, the shin's lower arm was detached from its own spine,
    and the roll-bracket tie was floating. All closed, and a test now enforces
    one rigid piece per body so it cannot come back.
    Closing them pushed the leg structure into the wh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
    [model.py]
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2026-07-26 Port the shin to CAD, derive every mass from it, re-verify the balancer
    cad/shin.py builds the shin as a real printable part from the dimensions the
    sim already uses, adding what a parametric sketch lacks: a hub to bolt onto
    the knee servo horn, a bearing bore for the ankle pitch axis, M2 clearance
    holes for the ankle servo, and a lightening pocket. STEP and STL out.
    It weighs 17.3 g at 60% infill, against the 100 g the model assumed.
    cad/masses.py then derives every body: printed structure by volume, plus the
    servos whose CASES bolt to it, plus bought parts. That fixes the long-standing
    error of leaving 100 g in the shin for a wheel servo that actually lives on
    the roll bracket 110 mm fur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
    [masses.py, model.py, shin.py]
2026-07-26 Add a part viewer, and delete a pocket that looked fine only in code
    cad/view.py renders an exported STL from three angles into one PNG, using a
    bare MuJoCo scene, so parts can be eyeballed without a CAD GUI.
    Looking at the shin immediately paid for it. The lightening pocket cut a 10 mm
    slot clean through a 20 mm spine, leaving a thin-necked keyhole, which quietly
    invalidates the 0.73 mm stiffness figure in docs/bom.md - that assumes a solid
    section. It saved about 2 g on a 17 g part, so it is gone. Shin is now 20.6 g
    and the total is 1720 g.
    [model.py, shin.py, view.py]
2026-07-26 Review the shin for manufacture, and fix three faults it would have shipped
    Reviewed before porting the other links, since the same mistakes would
    otherwise be repeated seven more times.
    The knee hub had no attachment at all: the horn bolt circle sat at 7.5 mm
    radius inside a 10 mm bore, so all four M2 holes cut air. The part could not
    have been bolted to the knee servo. Now a 4 mm bore, bolts at 8 mm, 13 mm hub.
    The arm was the weak member at 18.8 MPa on a 3x design load - only 2.1x on
    PETG's 40 MPa in-plane, and close to its ~20 MPa across layers. Deepened
    10 -> 14 mm, now 10.8 MPa and 3.7x.
    The ankle servo's mounting bolts were 12 mm apart. Its reaction torque peaks
    at 1.63 N.m, so tha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
    [model.py, shin.py]
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2026-07-26 Port the thigh, and widen it for the load nothing reacts
    The governing load in the whole leg turns out to be at the hip, and no servo
    carries it: with no hip roll joint, a lateral force at the contact patch is
    reacted entirely by the structure. At the design load that is 9.5 N.m, and at
    the shin's 12 mm width the margin was 2.0x - the thinnest anywhere in the
    robot. The thigh spine is 16 mm wide instead, giving 3.6x. Fore/aft was never
    the issue there; the hip servo's own peak works out at 25x.
    The knee servo mount has to reach AROUND the servo rather than bolt beside it.
    Its case occupies exactly the y band the shin's hub needs, so bolting to the
    outboard face would put the bracket through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
    [assembly.py, masses.py, model.py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]
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2026-07-26 Assemble the whole robot from the CAD parts
    cad/robot.py places every part by the SIMULATOR's kinematics - pose the sim,
    read each body's world transform, hang that body's CAD mesh on it - so a
    disagreement between CAD and sim shows up as a visibly broken picture rather
    than a quietly wrong one. Right-hand parts are the left meshes mirrored in y.
    Renders both modes.
    cad/assemble_check.py intersects every pair of real solids at those poses:
    19 solids, 0 interfering pairs, in wheel mode and foot mode. Now in the suite,
    which is 45 tests and still runs in 35 s.
    The first version of that check was worthless and looked fine. It dropped the
    meshes into a MuJoCo scene and counted contacts, report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
    [assemble_check.py, robot.py]
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2026-07-26 FEA every printed part in five materials
    Loads are measured off the sim rather than estimated: d.cfrc_int is the exact
    wrench crossing each joint, inertial and contact terms included. Its torque is
    taken about the subtree com, not the joint, so it has to be translated first -
    read straight it is tens of times too large. Closes against statics at the
    knee, 6.10 N against 6.10 N.
    Solver is TET10, not TET4. A constant-strain tet cannot represent bending at
    all and would have under-reported every part in this robot. Verified against a
    cantilever: deflection +1.9%, mid-span stress +3.1%.
    Three faults found, all geometry rather than material:
    The roll bracket's two members overlap in a 2.00 x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
    [fea.py, loads.py, stress.py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]
2026-07-26 Real parts and real inertia in the sim; strengthen three parts to print
    TASK 2 - the CAD parts in the simulator.
    Mass per body was already derived. Where that mass SITS was not: each link's
    inertia still came from whatever primitive carried it, a 28 mm capsule
    standing in for an L-shaped part with a servo bolted to one side. Now composed
    from the real B-rep solid plus the servo and bought-part boxes, parallel-axis
    about the composite centre of mass.
    The ankle's centre of mass turned out to be 75 mm from where the stand-in put
    it: the roll servo really does hang 76 mm aft of the axle, and the box
    modelling it sat 23 mm forward. A 98 mm error on a swinging link, per leg.
    Correcting the dist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
    [ankle.py, inertia.py, loads.py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]
2026-07-26 Draw the ankle-pitch joint, and rebuild what was dodging it
    The joint did not exist: the shin's bore was 52.8 mm off the axis the sim
    rotates about, the yoke had no matching feature, and assembled the two parts
    came no closer than 10.3 mm with nothing between them. The roll bracket's
    contorted shape was three rounds of crabbing round a post that was only there
    to carry that wrong bore.
    cad/envelope.py now writes the clearances down as SOLIDS instead of prose and
    intersects candidate geometry against them. Asked where the bearing may go, it
    finds exactly two bands - y = -80..-47 and y = +57..+80 - because everything
    between is inside the wheel in one of its two shapes or inside the wheel-dri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
    [ankle.py, envelope.py, fea.py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]
2026-07-27 Add a printability check, and measure servo torque margin
    Everything so far asked whether the parts are strong and whether they fit
    together. Neither notices a 1.4 mm web, an overhang through a bearing bore, or
    a part that does not fit the bed - the things that turn a correct design into a
    failed print.
    part footprint mm bed overhang thin
    thigh 133 x 60 x 32 yes 19% none
    shin 127 x 58 x 51 yes 18% none
    ankle yoke 65 x 16 x 69 yes 15% none
    roll bracket 45 x 31 x 30 yes 19% none
    chassis 180 x 79 x 90 yes 2% none
    Servo torque, measured over the whole envelope rather than assumed: p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
    [printability.py]
2026-07-27 Measure the real servo, design the wheel, size the belt
    NOT MERGEABLE YET: applying the real servo dimensions breaks 5 tests and 12
    clearance pairs. That is the finding, not a regression - see below.
    SERVO. Every servo dimension in this project was a number I made up from a
    product listing. Four of the five printed parts bolt to a servo, so those
    numbers set every mounting face in the robot. cad/servo.py now reads them off
    TheRobotStudio's SO-ARM100 STEP model of the same part, with OCC rather than by
    typing:
    case height 35.4 -> 39.60 mm and the 4.2 mm is ALONG THE SHAFT, which
    is exactly where the horn clearances are
    horn bolts r=8.0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
    [ankle.py, model.py, servo.py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]
2026-07-27 Fit the real servo, draw both drives, and write up what is verified
    Finishes the real-servo pass: 53 tests green, all clearance checks clean.
    CLEARANCES. Applying the measured servo removed 4.2 mm that never existed and
    broke 16 pairs. Fixing them moved the shin's whole outboard route (x 28 -> 37,
    pitch bearing y 68 -> 71), the ankle servo up 6 mm, the yoke's pitch arm out,
    the chassis shelves, and split the side plates - the hip servo lives INSIDE the
    chassis and its boss passes out through a notch nobody had drawn.
    BELT. GT2 20T -> 40T, 94 teeth, 188 mm, 15 mm wide. The centre distance falls
    on a stock belt to within a tenth of a tooth. 15 mm and not 9 because the
    measured 1.68 N.m joint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
    [ankle.py, belt.py, chassis.py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]
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2026-07-27 Give the wheel tread and a tyre that is actually held on
    The tyre was a slip fit. Bore and rim were both exactly r = 37.0, so the
    interference check read 0.00 mm3 and passed - a fit of precisely nothing,
    certified as a good fit. Wheel torque at the rim is about 78 N at stall, which
    a smooth zero-preload interface does not carry, so it would have spun the first
    time the robot drove, and nothing stopped it walking off the open end either.
    press fit 0.35 mm radial. The overlap IS the fit now, and what is checked
    is that it matches the interference designed in: 1570 mm3
    against 1539 predicted.
    bead 12 castellated teeth doing two jobs, an axial stop a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
    [inertia.py, loads.py, masses.py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]
2026-07-27 Check clearance, not just interference - and find two joints that needed it
    assemble_check reported "0 interfering pairs" and had been reporting it all
    along, because interference was the only thing it tested. A pair 0.1 mm apart
    read exactly like a pair 20 mm apart. Two real faults were sitting inside that
    blind spot, and the print services quote +/-0.3 mm on each part, so any drawn
    gap under about 0.8 mm is inside the tolerance band and is not really a gap.
    wheel / roll bracket 0.1 mm. The arm ran parallel to the whole face of a
    part that turns at 40 rad/s, from the hub out to the
    rim. A drawing clearance, not a manufacturing one, in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
    [ankle.py, assemble_check.py, test_stress.py]
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2026-07-27 Specify every fastener, and check the screws point where the holes are
    Item 2 of road-to-order. Until now every bolt hole in the CAD was a clearance
    hole into air: nothing said what screw went in it, what it threaded into, or
    how long it had to be, and the robot had no bolt list at all.
    The decision, written down in cad/fasteners.py:
    part -> servo CASE M2 self-tapping through a 2.2 mm clearance hole, into
    the servo's own 1.5 mm pilot. The servo supplies the
    thread, so the printed part needs nothing but a clean
    hole and there is no nut.
    part -> servo HORN M2.5 into a heat-set insert in the printed part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
    [fasteners.py, servo.py, test_stress.py]
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2026-07-27 Stack the tolerances along the assembly chain, not pair by pair
    Item 5 of road-to-order. Every gap in this project was measured on nominal
    geometry, and the running-clearance check added earlier compared single pairs
    against a flat 0.8 mm. Neither is the real worst case: the error between two
    parts is not one tolerance, it is one PER INTERFACE separating them along the
    chain. The wheel is four joints from the chassis, so it can be five tolerances
    out relative to it, not one.
    Analytic rather than a perturbed solve, for a reason worth recording: growing
    these solids by 0.3 mm to test it directly fails outright in OCC, they have too
    many features for the offset to close. The analytic version i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
    [assemble_check.py, test_stress.py]
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2026-07-27 Model the cables, the one thing here that could force a reprint
    Item 4 of road-to-order. There was not one cable, channel, tie point or strain
    relief anywhere in this project - ten daisy-chained bus servos, a lead across
    every joint, and one of those joints turns 90 degrees.
    The connector is measured rather than guessed: six pins at x = -0.55,
    z = -16.90 on the rear face opposite the shaft, two 3-pin groups at y = +/-5.2
    on a 2.40 mm pitch.
    Runs are STRAIGHT LINES between ports, which is deliberate and is the whole
    epistemic value of the thing: a straight line is the shortest possible path, so
    a run this reports as blocked is blocked for every real routing too. A run it
    reports as clear is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
    [test_stress.py, wiring.py]
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2026-07-27 Measure the horn bolt pattern instead of assuming it: it is M3, not M2.5
    The horn was the top unknown - four of the five printed parts bolt to one, and
    the pattern was never verified because the horn is a separate bought part and
    the servo STEP holds one solid, the bare case.
    It did not need hardware after all. A part that MATES with the horn carries the
    horn's pattern as its own clearance holes, and TheRobotStudio publish theirs:
    Rotation_Pitch_SO101 two patterns r = 1.60 +/-4.95 x +/-4.95
    Wrist_Roll_Pitch_SO101 two patterns r = 1.60 +/-4.95 x +/-4.95
    Upper_arm_SO101 two patterns r = 1.50 +/-4.95 x +/-4.95
    Six patterns, three parts, agreeing on positio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
    [fasteners.py, masses.py, model.py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]
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2026-07-27 Put the real wheel in the live sim, not a grey cylinder
    serve.py loads with meshes=True and swaps in the real CAD parts, but MESH_STEM
    only covered the thigh, shin, ankle yoke, roll bracket and chassis. So driving
    the robot around showed the wheel as the primitive stand-in - the one part that
    has changed most, with the tread, the press fit and the retaining bead all
    invisible.
    Two things stopped it being a one-line addition, and both are assumptions
    baked into the old swap:
    - the wheel is TWO meshes in two materials, a PA6-CF body and a TPU tyre,
    where MESH_STEM assumes one mesh per link
    - it needs a rotation the others do not, because its CAD spins about z and
    the sim body spi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
    [model.py]
2026-07-28 Stop the FEA exhausting the machine, and fix a mesh that reported a fake failure
    THE CEILING FIRST, because it cost the user real work. A direct sparse
    factorisation is exact and fast and its memory is NOT linear in the mesh: a
    65k-node solve reached 32 GB here, the kernel went looking for something to
    kill, and it took the user's IDE (9.5 GB) with it. Nothing warned. The solve
    got slower and then an unrelated application was gone.
    cad/fea.py now refuses above 55k nodes with the number and the reason, instead
    of discovering the limit by exhaustion. It caught the leg assembly at 62.6k on
    its first run, which would otherwise have gone the same way - filleting the
    shin and yoke gave the curvat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
    [fea.py, stress.py, test_stress.py]
2026-07-28 Close the chassis, soften the edges, and put a name on the side
    The ask was to make it look less ungainly without changing what it does. Most
    of what looks ungainly is load-bearing - the sprawl is the STS3215 being a
    45.4 x 24.8 x 39.6 brick with its shaft 10.2 mm from one end, so its swept
    radius about its own joint is 35.2 mm where a round coaxial actuator would be
    12. Every joint has to make room for three times the actuator. That is bought,
    not drawn, and it is the whole difference from the humanoids this gets compared
    to. But three things were genuinely available:
    THE CHASSIS, which is the one that was really an engineering fix. It was open
    front and back - a U-section, the worst shape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
    [ankle.py, chassis.py, decal.py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]
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
